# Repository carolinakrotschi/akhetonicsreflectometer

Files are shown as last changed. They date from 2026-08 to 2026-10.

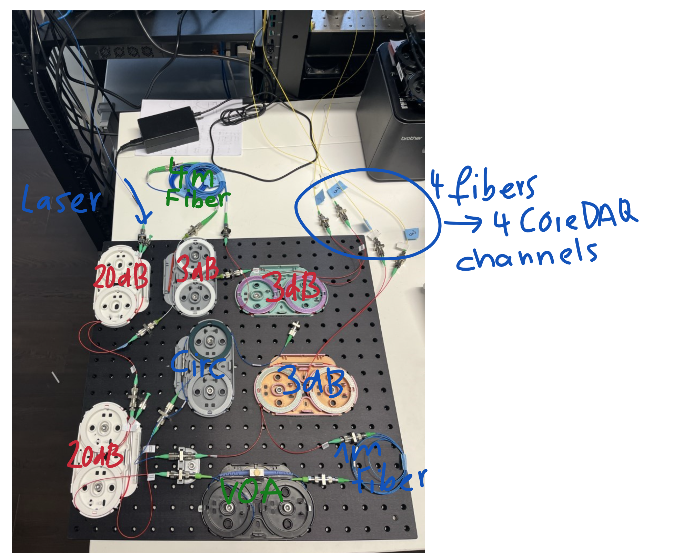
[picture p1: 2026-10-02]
general documents/setuplab.png

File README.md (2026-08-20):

# OFDR Reflectometer — what's in this folder

Quick orientation. For the physics/background, read `HANDOVER.md` first, then
`docs/handover_explained.md`. For the step-by-step lab procedure, see
`docs/measurement_procedure.md`.

## Active pipeline (main directory)

The setup as of 2026-08-18 uses the **old** trigger mode: EXFO laser sweep,
1 pm wavelength grid, 2 detector channels (Ch1/Ch2).

| Script | What it does |
|---|---|
| `process_reflectogram.py` | Main processing pipeline: loads an EXFO JSON scan, balances the two channels, corrects the frequency axis for the laser's tuning error, FFTs to a reflectogram, reports peak positions/widths, writes a CSV + PNG. This is the everyday tool. |
| `diagnose_artifacts.py` | Five discriminator tests for telling a real reflection apart from an artifact: `pm-am` (additive vs. multiplicative noise), `compare` (is a feature fixed/calibratable or a random per-scan realization?), `fold` (where would a reflector beyond Nyquist alias to?), `tuning` (measure the laser's actual sweep error), `alias` (single-file peak/aliasing-order check, or the definitive two-scan pair test with different wavelength steps). Run these *before* trusting an unexplained feature. |
| `plot_tuning_diagnosis.py` | Rebuilds the two-panel "MZI peak vs. sweep tuning error" figure (the one originally saved as `george/real_data_diagnosis.png`) for any scan, reusing `process_reflectogram.py`'s functions directly. |

The following three belong to the **new**, not-yet-built setup: free-running
acquisition with an auxiliary Mach-Zehnder interferometer ("aux MZI", the
"ruler") providing the frequency reference instead of a wavelength table,
4 channels. **Ch1/Ch2 = aux MZI (the ruler), Ch3/Ch4 = measurement
interferometer with the test fiber** (confirmed 2026-08-18 against the
real wiring — double-check this against the bench before trusting a scan).

| Script | What it does |
|---|---|
| `calc_sweep_parameters.py` | Desk calculator: given point count / sweep speed / span, computes resolution, Nyquist range, and whether the aux MZI's own signal fits inside that range. Use this before touching hardware. |
| `simulate_aux_data.py` | Generates synthetic 4-channel free-running data with *known* ground-truth reflector positions, including realistic imperfections (sweep bow, tuning ripple, gain drift, noise). Used to validate `process_reflectogram_aux.py` against a known answer before trusting it on real data. |
| `check_aux_interferometer.py` | Acceptance test for the aux MZI itself: contrast, monotonicity (laser must never tune backward), calibration (tau_aux via fringe counting), and laser quality (slow bow / fast ripple), measured cleanly through the aux signal. Run this before trusting anything the new setup measures. |
| `process_reflectogram_aux.py` | The new 4-channel processing pipeline: same balanced-subtraction/window/FFT/peak-report core as `process_reflectogram.py`, but the frequency axis comes from the aux MZI's phase instead of a wavelength table. |

## `tools/` — standalone helper scripts

Not part of the day-to-day pipeline above, but useful on their own.

| Script | What it does |
|---|---|
| `plot_band_comparison.py` | Compares the 6-32cm "dirt band" across several raw scans on one plot (built 2026-08-18 for the terminator investigation, see `raw_data/README.md`). |

(2026-08-18: `check_aliasing.py` was merged into `diagnose_artifacts.py` as
its `alias` subcommand — it overlapped with `fold`/`compare`/`pm-am` there.
`simulate_scan_data.py` and `plot_fsr_vs_wavelength.py` were retired as
dead weight — the former only validated the now-legacy CSV pipeline, the
latter was a one-off tied to a folder that no longer exists. All three are
still in git history if ever needed again.)

## `legacy/` — historical record only, no scripts left

`legacy/CHANGES.md` is the only thing left here: the documented bug list
from the very first (buggy) reflectometer attempt. The scripts themselves
(`reflectometer_v1_buggy.py`, `reflectometer_v2_fixed.py`, and the generic
CSV-based `reflectometer_csv_generic.py`) were all deleted 2026-08-18 as
fully superseded by `process_reflectogram.py` — recoverable from git
history if a plain-CSV or pre-EXFO-JSON input format is ever needed again.

## Other folders

- `raw_data/` — raw EXFO JSON scans, named `<date>_<condition>.json`; see `raw_data/README.md` for what each one is and the current findings.
- `results/<date>/` — generated CSVs and plots, one subfolder per day.
- `docs/` — explanatory and planning documents written for/with Carolina.
- `george/` — frozen reference copies of the files as originally handed over by the supervisor. Not used for running anything; the active copies above are what you actually execute.
- `logs/<date>.md` — daily work journal (see `CLAUDE.md` for the rule that maintains it).

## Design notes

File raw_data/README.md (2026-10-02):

# Raw data — file index

**Detector.** Every file listed below up to 2026-09-17 was recorded with the
Mk1 **LINEAR** coreDAQ demo unit. Since then both coreDAQs are Mk2 **LOG**
units (SN0001, SN0002). A Mk2 file carries a `detector` block in its header
(unit, serial, rate, clamp fractions, R(λ) correction); a file without one is
Mk1. For new entries add a column **Detector** (e.g. `Mk2 LOG SN0001,
100 kHz`) and note any clamp the recorder reported. Read all of them through
`tools/scan_io.py` -- see `md files/HANDOVER.md` §7.

**Scans from 2026-09-11 onwards ARE in the repository, as `.npz`.** The raw
`.json` still cannot be pushed -- each one is ~155 MB, past GitHub's hard
100 MB per-file limit -- but the same data stored as a compressed `.npz`
is 11-13 MB, a factor of ~13 smaller, and the conversion is **lossless**:
the four channel arrays are kept as float64 and verified bit-identical
after the round trip, and the wavelength axis is kept in full because it
turned out not to be linear (it deviates up to 0.147 nm from a straight
line). Converted with `tools/json_to_npz.py`; `process_reflectogram_aux.py`
reads `.npz` directly, and a reflectogram computed from the `.npz` is
bit-identical to one computed from the `.json`.

**Older raw JSON: not tracked in git** (`.gitignore`'d): with the current 1M-datapoint sweeps,
raw JSON scans run ~150 MB each, past GitHub's 100 MB file limit. Only the
`_trimmed1530.npz` derivative of each scan (produced during processing) is
committed. This file stays local-only; the mapping below is the record of
what exists on disk.

All files: EXFO sweep 1505.06-1624.96 nm, 119,921 points, old 1-pm trigger mode,
2 channels (Ch1/Ch2). Format: see `george/HANDOVER.md` section 2.

Note: `2026-08-20_laserdirektangeschlossen.json` uses power keys in `[W]`
(`"Ch1 [W]"` etc.), not `[mW]` like every other file listed here -- the
instrument apparently switches units depending on power range. Convert before
comparing medians against other scans.

| File | Date | Condition at the test port |
|---|---|---|
| `2026-08-18_open_end.json` | 2026-08-18 | No terminator, fiber end open (baseline, formerly `scan_s0.json`) |
| `2026-08-18_no_fiber.json` | 2026-08-18 | No test fiber connected at all (formerly `scan_s1new.json`) |
| `2026-08-18_terminator1.json` | 2026-08-18 | Terminator 1 |
| `2026-08-18_terminator2.json` | 2026-08-18 | Terminator 2 |
| `2026-08-18_10db_coupler.json` | 2026-08-18 | 10dB coupler inserted |
| `2026-08-19_firstscanwith4channels.json` | 2026-08-19 | First test scan, new 4-channel aux-referenced free-run setup (600 pts, 1505-1625 nm, Ch1/Ch2 = aux MZI, Ch3/Ch4 = measurement). Processed with `process_reflectogram_aux.py`. |
| `2026-08-19_secondscanwith4channelsmorepoints.json` | 2026-08-19 | Same setup, 60,000 pts, 1505-1625 nm. |
| `2026-08-19_1miodatapoints.json` | 2026-08-19 | Same setup, 1,000,000 pts, 1520-1570 nm (scan_S5 of `md files/measurement_procedure.md`). First 200,000 pts (wl<1530nm) are detector-saturated; drop them (`_trimmed1530.npz`) before trusting anything -- with them included, acceptance test **fails monotonicity** (2.4-25% backward steps depending on channel pairing, limit 0%). Channel-pairing investigation (see `logs/2026-08-19.md`/`logs/2026-08-20.md`): aux = Ch2/Ch4 (dL≈4.24m), measurement = Ch1/Ch3 -- opposite of the 2026-08-18 convention above. |
| `2026-08-19_deltaLwirklich1m.json` | 2026-08-19 | Same setup/format. Measurement-interferometer LO arm rebuilt to a real, physical ~1 m round-trip match (test fiber ~1.04 m one-way, confirmed by tape measure). Same first-10nm saturation as above; use `_trimmed1530.npz`. Aux calibration matches the scan above almost exactly (dL≈4.24m) -- confirms only the measurement arm changed. Reflectogram (aux=Ch2/Ch4, meas=Ch1/Ch3) shows the real fiber-end peak at ~1061.7mm (matches the measured 1.04m length within 2%) plus an unexplained dominant peak at ~587.0mm (not fiber-related -- stable across re-coiling, see next row) and two nonlinear mixing artifacts (~1649mm sum, ~2121mm 2nd harmonic of the fiber peak). |
| `2026-08-19_deltaLwirklich1mneugerollt.json` | 2026-08-19 | Same as `deltaLwirklich1m.json`, fiber only re-coiled (same physical fiber, different bend routing) -- otherwise nothing changed. Confirms: 587.0mm peak unchanged in position/strength (supports it not being the fiber); ~1062mm fiber peak same position, 11dB weaker (consistent with added bend loss); ~1649mm sum-artifact got 13dB *stronger* (unexplained -- inconsistent with simple intermodulation, possible real multipath reflection). |
| `2026-08-20_3mfiber.json` | 2026-08-20 | **"3mA" fiber** (label introduced 2026-08-31 to distinguish from the physically different "3mB" fiber used on 2026-08-31 -- inferred lengths differ, ~3147mm vs ~2616mm relative to connector). ~3m fiber moved onto the measurement interferometer as its only fiber (old ~1m fiber + LO-match arm removed); aux dL backfilled with 3x1m segments instead. Main 587mm-family peak persists (4th confirmation, internal artifact); nothing at naive 3000mm; unexplained peak at 3734.5mm (later shown to be fiber-related but not matching the tape-measured 3.05m length directly -- see log). |
| `2026-08-31-ohnefiberallesnormalerstemessungdestages.json` | 2026-08-31 | No fiber, first measurement of the day. Monotonicity FAILS (0.0224%, localized contrast dip). See `logs/2026-08-31.md`. |
| `2026-08-31-ohnefiberallesnormalzweitemessungdestages.json` | 2026-08-31 | No fiber, second measurement of the day (repeat). Monotonicity PASSES. |
| `2026-08-31-ohnefiberallesnormaldrittemessungdestages.json` | 2026-08-31 | No fiber, third measurement of the day (repeat). Monotonicity FAILS badly (0.93%, real sweep anomaly, not just noise) -- dL/tau_aux from this scan unreliable, do not reuse. |
| `2026-08-31-ohnefiberandereaux1mfiber.json` | 2026-08-31 | No fiber; the aux's 1m fiber segment swapped for a different physical one (dL essentially unchanged, ~3.59m; contrast/monotonicity improved). |
| `2026-08-31-ohnefiberaux5m.json` | 2026-08-31 | No fiber; aux stretched to dL≈4.489m (labeled "aux5m" target). Best contrast of the no-fiber scans that config. |
| `2026-08-31-ohnefiberaux6m.json` | 2026-08-31 | No fiber; aux stretched further to dL≈5.39m (labeled "aux6m" target). Points/fringe dropping toward the ~4 warning floor. |
| `2026-08-31-1mfiberaux5m.json` | 2026-08-31 | ~1m fiber (no separate letter label), aux5m config (dL≈4.489m). Inferred length ≈912mm relative to connector. |
| `2026-08-31-3mfiberaux5m.json` | 2026-08-31 | **"3mB" fiber** (see note on `2026-08-20_3mfiber.json` above), aux5m config (dL≈4.489m). Inferred length ≈2616.5mm relative to connector. |
| `2026-08-31-3mfiberaux4m.json` | 2026-08-31 | **"3mB" fiber** on the measurement arm, aux4m config (dL≈3.578m; **aux arm itself built from "3mA" + "1mB" segments** -- "3mA" being the old 2026-08-20 fiber repurposed as aux filler, "1mB" a separate 1m fiber, both distinct from the measurement-arm "3mB"/"1mA" naming below -- confirmed by Carolina 2026-08-31 after an initial mix-up). Same physical measurement fiber as the aux5m scan above, inferred length ≈2615.5mm, confirms length is aux-config-independent. |
| `2026-08-31-3mplus1mfiberaux4m.json` | 2026-08-31 | **"3mB" fiber + "1mA" fiber in series** on the measurement arm (the 1m component here labeled "1mA" to distinguish it from the standalone `1mfiberaux5m` fiber, which has no separate letter); aux4m config, aux arm built from "3mA"+"1mB" (see note above -- these are DIFFERENT physical fibers from the measurement arm's "3mB"/"1mA", despite the confusingly overlapping letters). Inferred combined length ≈3523.8mm, vs. 2615.5+912.0=3527.5mm predicted from the two measurement fibers measured separately -- within 4mm (this match is what confirmed the measurement arm is "3mB"+"1mA", not "3mA"+"1mB", after Carolina's initial statement suggested the latter). |
| `2026-08-31-3mplus1mfiberaux4m_2.json` | 2026-08-31 | Repeat of the scan above (same physical setup: measurement arm "3mB"+"1mA", aux arm "3mA"+"1mB"). dL=3.5778 m (tau_aux=17.5193 ns) -- matches the first scan's 3.5782 m to 0.4 mm, confirms the aux4m build is stable between scans. |
| `2026-08-20_nofiberattheend.json` | 2026-08-20 | No-fiber control: test-port fiber removed entirely, everything else (incl. 3x1m aux setup) left as in `3mfiber.json`. Proves the ~587mm and ~518mm peaks are fixed internal reflections, unrelated to any DUT fiber (both persist with nothing connected). |
| `2026-08-20_laserdirektangeschlossen.json` | 2026-08-20 | Laser output connected directly to a detector, bypassing the interferometer network entirely (control/reference scan, not a reflectogram). Only Ch2 carries signal (~5.800 mW, flat to ~0.03% across the whole 1520-1570nm sweep, **no saturation ramp at the start** unlike every interferometer scan); Ch1/Ch3/Ch4 sit at the electrical noise floor (~0.1-0.5 uW). Confirms the laser source itself is flat and clean -- the detector saturation seen in the first 200,000 points of other scans is caused downstream (interferometer/detector combination), not by the laser. Note: uses `[W]` units, see note above. Plot: `results/2026-08-20/2026-08-20_laserdirektangeschlossen_channels.png`. |
| `2026-08-20_nofiberattheendandnotthorlabsconnector.json` | 2026-08-20 | Second no-fiber control: same as `2026-08-20_nofiberattheend.json` (test-port fiber removed) but with the Thorlabs connector swapped for a different, "normal" (non-Thorlabs) connector -- **not removed, replaced** (corrected 2026-08-20, see log). Same 1M-point/4-channel/1520-1570nm format, same first-200,000-point saturation, trimmed the same way (`_trimmed1530.npz`). Big result: the dominant fixed-internal-reflection peak moved from ~587.8mm to **467.1mm** (0 dB) -- first evidence tying that peak's position to the physical path length of whichever connector occupies that slot. See `logs/2026-08-20.md` for the full writeup. |
| `2026-08-20_nofiberattheendandnotthorlabsconnectorandfibercleaned.json` | 2026-08-20 | Same setup as the row above (no fiber at test port, same replacement "normal" connector #1 still installed), plus the fiber was cleaned. Same format/trimming. Main peak essentially unchanged (467.0mm vs 467.1mm, negligible) -- confirms the fixed reflector is unrelated to fiber cleanliness, consistent with it not being fiber-related at all. Noise floor is ~9dB higher than the previous scan (median -59.2dB vs -68.4dB in a quiet 700-1600mm window), matching a lower aux contrast (min visibility 0.776 vs 0.846) -- explains why many more small peaks cross the fixed -50dB reporting threshold; not a new physical feature. See `logs/2026-08-20.md`. |
| `2026-08-20_nofiberattheendandnotthorlabsconnectorandfibercleanedandnewconnector.json` | 2026-08-20 | Same setup as the row above, but connector #1 was swapped for a SECOND, different "normal" connector (#2) -- so far: Thorlabs -> normal connector #1 -> normal connector #2, never actually connector-free. Same 1M-point/4-channel/1520-1570nm format, but **saturation ramp lasts ~13nm this time** (vs ~10nm on every earlier 2026-08-20 scan) -- trimmed to `_trimmed1533.npz` (dropped first 260,000 pts, wl<1533nm) instead of the usual `_trimmed1530.npz`. Big result: main peak moved back to **589.7mm**, into the same ~587-590mm family seen throughout the day with the ORIGINAL Thorlabs connector in place -- confirms the peak's position tracks the physical path length of whichever connector occupies that slot (connector #2's length happens to be close to the Thorlabs one's; connector #1's was ~120mm shorter), not the identity of one specific connector. The ~518-521mm secondary cluster also reappeared. See `logs/2026-08-20.md` for the full writeup and `HANDOVER.md` section 2 for the updated standing conclusion. |
| `2026-08-20_nofiberattheendandnotthorlabsconnectorandfibercleanedandnewconnectorneueeinschwingzeit.json` | 2026-08-20 | Same nominal setup as the row above (connector #2), but recorded AFTER a fix to the akhelabs acquisition software (`exfo_window.py`): a new "Settle margin (nm)" field makes the laser start its physical sweep that many nm before the requested start wavelength, then crops the pre-roll back out after acquisition -- so the returned data no longer contains the ~10-13nm detector-saturation transient at all. 833,333 points, 1520.00-1570.00nm, no wavelength trim needed (saved whole as `_full.npz`, verified clean in 0.5nm bins from the very first sample). Resolution improved from 22.61um (previous scan, 13nm had to be trimmed) to **16.59um** (full ~50nm span used) -- see `logs/2026-08-20.md` for the comparison plot. Note: aux dL (3.593m) and the main peak position (495.6mm) both differ noticeably from the immediately preceding connector-#2 scan (4.276m / 589.7mm) -- the physical setup was evidently touched again while testing the new firmware feature; not yet reconciled, see log. |

| `2026-09-11-11-36_3mfiber.json` | 2026-09-11 | ~3 m fiber on the measurement arm, LinaWindow/coreDAQ-LIN, 1520-1570 nm. **Not yet processed** -- recorded 40 min before the chip scan below, same session. |
| `2026-09-11-12-16hhi1fiber7.json` | 2026-09-11 | **Sixth HHI chip measurement -- fiber 7 = `b25`, the STUB negative control. Passed.** Facet A at 1673.3662 mm (0 dB, -3 dB width 33.2 um vs 43.1 um window limit = isolated single reflector), pigtail 1099.492 mm, noise floor -69.2 dB, and **nothing behind facet A** beyond the satellite skirt (max -40 dB in +5..+12 mm, -44 dB in +20..+60 mm). Three conclusions: (1) the rule **b = 32 - fiber** is confirmed a second time, independently of any path-length assignment; (2) **there is no "SSC-internal reflector" at +3.1..3.7 mm** -- a stub contains a full SSC and shows nothing there, so that earlier interpretation is retracted; (3) **"strongest peak = facet A" does not hold generally** -- facet A is the fiber/chip interface reflection, set by glue/gap/index match alone, and varies by >45 dB across channels (+36 dB vs the internal reference here, -9 dB in the top loopback), so facet A must be identified via the pigtail-length family (1094.4..1099.5 mm over 6 fibers), not via peak height. tau_aux = 20.3811 ns, monotonicity passes. |
| `2026-09-11-12-16hhi1fiber30.json` | 2026-09-11 | **Fifth HHI chip measurement -- fiber 30.** Cleanest scan of the day (noise floor -71 dB, single reflector with -3 dB width 49.8 um vs 43.1 um window limit). Facet A at 1670.2383 mm (pigtail 1096.312 mm), one dominant reflector at **+9.2069 mm = 2685.8 um of on-chip waveguide -- which matches NO channel in the layout** (nearest path end is b3 at 2489.6 um, 28 resolution cells away). **This refutes the "fiber 27 was a misread 30" hypothesis**: the two scans have different pigtails (1095.32 vs 1096.31 mm) and different dominant reflectors (+14.6148 vs +9.2069 mm), so they are different couplers. **Consequence: the n_SSC/n_waveguide split reported from the 3-point fit is RETRACTED** -- it relied on assigning the +14.6148 mm peak to b2's MMI input, which no longer holds; that 2.3 um agreement was most likely coincidence. What stands: n_g,chip = 3.4803 +- 0.008 from the two loopbacks alone. tau_aux = 20.3808 ns, monotonicity passes. |
| `2026-09-11-12-16hhi1fiber6.json` | 2026-09-11 | **Fourth HHI chip measurement -- fiber 6.** Confirms the fiber-to-coupler rule **b = 32 - fiber** (position from top = fiber - 3, 29 couplers on fibers 4..32): without the +3 offset fiber 6 would be `b23`, a stub with 18 um of waveguide, which cannot produce the observed -1.31 dB peak 15 mm into the chip plus a 70 mm forest of 448 peaks. Quantitatively consistent with `b26` (run 5126.8 um, implied pigtail 1095.84 mm) but **not separable from b2** -- they differ by 0.378 mm while the multipath forest (mean peak spacing 0.156 mm) limits facet-A anchoring to +-0.4 mm. Methodological lesson: **circuit channels are unusable for precision work** (decoder has many MMIs + 2 ring resonators -> recirculation); only the two loopback pairs give clean geometry. tau_aux = 20.3815 ns, monotonicity passes. |
| `2026-09-11-12-16hhi1fiber27.json` | 2026-09-11 | **Third HHI chip measurement -- single-ended channel, fiber 27.** Named "kanal24" but the measurement identifies it as **GDS coupler `b2`**, not b24: facet A at 1669.3593 mm (fiber 1095.316 mm), dominant peak (0 dB, the strongest in the whole scan) at +14.6148 mm = the input facet of an MMI 1x2 splitter at the end of b2's 4967.278 um waveguide run -- predicted 14.6214 mm, i.e. **6.6 um off over 14.6 mm (0.045%)**. tau_aux = 20.3814 ns, monotonicity passes, best contrast of the day (0.640). Combined with the two loopback scans this gives 3 measurements for 2 unknowns: **n_g,SSC = 3.4808 +- 0.0121 and n_g,waveguide = 3.4782 +- 0.0078, agreeing to 0.07%** -- so SSC and waveguide have the same group index and the uniform-n_g assumption holds. Fiber-to-channel mapping still unconfirmed; the only simple rule matching fiber 27 -> b2 is fiber n -> b(29-n). |
| `2026-09-11-12-16hhi1fiber32.json` | 2026-09-11 | **Second HHI chip measurement -- the BOTTOM loopback pair `b0`/`b1`** (design loop 556.5494 um, chip path 2956.55 um), same setup as the scan below, only re-plugged to the other coupler pair. 988,536 pts, 1520-1570 nm. tau_aux = 20.3807 ns (stable to 0.01% vs the top-loop scan), monotonicity passes. Facet A 1668.3752 mm (-16.6 dB), facet B 1675.3923 mm (-4.1 dB) -> **chip path dz = 7.0171 mm -> n_g,chip = 3.4842**, which agrees with the top pair's 3.4765 to **0.22%**. Differential vs the top pair: dz shrinks by 0.1825 mm for an 83.577 um shorter design loop = **77.0 um of on-chip waveguide measured SSC-free** (one resolution cell = 7.0 um physical). The middle reflectors stay put in both scans -> SSC-internal, not the loop ends. Pigtails here: 1094.4005 / 1095.1139 mm (per-channel, glued). Couples better than the top pair. |
| `2026-09-11-12-16hhi1fiber4.json` | 2026-09-11 | **First HHI chip measurement -- the TOP loopback pair `b27`/`b28`.** Measurement arm = MZI -> ~1 m fiber (SQS Vlaknova Optika, FC/APC, SM, no. 0103254561) -> HHI chip 1, **both** edge couplers of the top-left pair are pigtailed with ~1 m fibers (measurement arm -> fiber 1 -> chip loop -> fiber 2 -> open end, which provides the back-reflection); on-chip link is the 640.13 um loop (see `logs/2026-09-11.md` for the GDS length extraction). 988,536 pts, 1520-1570 nm. tau_aux = 20.3809 ns (dL = 4.1622 m), monotonicity passes (0.0000%). Chip input facet at 1670.23 mm (-9.1 dB) = +1096.30 mm past the fixed internal 573.93 mm reference; chip end facet at +7.200 mm, two intermediate reflectors at +3.135/+4.064 mm (2x3.135+0.929 = 7.199, symmetric 3-section path = SSC + loop + SSC). Full path vs. design 3040.13 um gives n_g,chip = 3.477. Open end of fiber 2 found at 2773.625 mm (-36.8 dB) = +1096.199 mm past the chip, i.e. **the two ~1 m fibers match to 0.099 mm** (1096.298 vs 1096.199 mm) -- independent confirmation of the whole chain. The +-0.70/+-1.53 mm satellites are instrument artifacts (ring the 573.93 peak identically). |

**Finding (6-32cm band, see `results/2026-08-18/band_6_32cm_comparison.png`):**
Terminator 1, Terminator 2, and the 10dB coupler all sit at approx. -52 to
-54 dB — essentially identical to `open_end` (-52.6 dB). Only `no_fiber` is
noticeably lower (-68.8 dB, noise floor). None of the tested terminators
effectively suppresses the reflection; the suspicion falls on Rayleigh
backscatter along the whole patchcord, or the near-end connector
(circulator <-> patchcord), rather than the far end. Next test discussed:
a short patchcord (<35 cm) to distinguish between the two hypotheses.

An earlier terminator attempt (`scan_s1.json`, deleted before 2026-08-18) had
an even louder band (-35.8 dB) — cause unresolved, file no longer available.

**Test fiber length (2026-08-18):** confirmed 50 cm one-way (1 m round trip).
`python diagnose_artifacts.py fold 0.5` shows this is BEYOND the old setup's
Nyquist range (0.417 m) and folds to **0.334 m (33.4 cm)** as an undersampled
band (1.67 points/fringe) — right at the edge of the observed 6-32cm dirt
band. This means the far-end reflection itself likely IS a real contributor
to that band (aliased, not resolvable), on top of/instead of the Rayleigh
backscatter hypothesis above. With the current 1-pm trigger mode, no
terminator or connector fix can turn this into a clean peak — the fiber is
simply longer than this mode can resolve unambiguously. The Aux-referenced
setup (~7 m Nyquist range) is required to see it cleanly at its true 50 cm
position.

**Open discrepancy:** confirmed 2026-08-18 to be the same physical patchcord
as the one behind the ~1.046 m estimate in `HANDOVER.md` §5 (2026-08-12) --
but the two lengths don't reconcile by a simple convention mixup (`fold 0.5`
and `fold 1.046` predict different apparent band positions). See the
"Test fiber length" note in `HANDOVER.md`'s hardware section for the
candidate explanations and the suggested `alias` pair test to settle it.

## Ligentec-SiN-Chip (Faserarray an der unteren Kante, 95 Kanaele)

**Chip-Praefix-Konvention (ab 2026-09-16):** alle Scans bis einschliesslich
2026-09-15 stammen vom selben physischen Chip, **MAP2672** -- ihre
rawdata- und results-Dateien wurden deshalb nachtraeglich mit
`2672_ligentechhi_` praefigiert. Ab 2026-09-16 wird ein neuer Chip,
**MAP2680**, vermessen; neue Scans dieses Chips sollten entsprechend mit
`2680_ligentechhi_` beginnen, damit rawdata/results-Dateinamen allein
erkennen lassen, von welchem physischen Chip sie stammen. Ausgenommen von
der 2672-Umbenennung: `raw_data/hhi_ligentec/` (gemeinsame GDS-Designdatei,
nicht chipspezifisch) und die `..._2m07cmfiber...`-Scans (laut Tabelle
unten explizit **kein Chip** angeschlossen).

**MAP2680 traegt elektrische Kontakte (Bondpads/Leiterbahnen), MAP2672
nicht.** Auch unangeschlossen koennen sie die Reflektogramm-Struktur nahe
der Facette beeinflussen (zusaetzliche Streuzentren/Reflexe durch
Metallisierung). Erster Hinweis 2026-09-16: Faser 1 auf beiden Chips zeigt
in der auf den eigenen Peak zentrierten Ansicht rechts vom Peak aehnliche,
links vom Peak abweichende Struktur -- siehe `logs/2026-09-16.md`. Noch
nicht verifiziert (z.B. gegen GDS-Kontaktlayout oder einen Kontrollscan);
offene Hypothese, beim Interpretieren chipuebergreifender Strukturvergleiche
mitdenken.

Alle Scans: neuer PM-Aufbau, freilaufend, 4 Kanaele (Ch2/Ch4 = aux,
Ch1/Ch3 = Messung), **1520.00-1570.00 nm, 988,536 Punkte**, tau_aux
~20.633 ns (aux dL 4.21 m). Aufloesung 16.6 um faseraequivalent,
Nyquistbereich 8.0 m. Kanalnummer = 96 - Fasernummer.

Gemeinsamer interner Anker fuer alle diese Scans: **529.43 mm**; auf ihn
werden die Pegel normiert, weil die alten Anker (574/587 mm) nach dem
PM-Umbau weg sind.

| File | Datum | Faser -> Kanal | Was dahinter liegt | Facette A |
|---|---|---|---|---|
| `2672_ligentechhi_2026-09-14-16-19_ligentecnofiber.json` | 2026-09-14 | — | **Kontrolle**, nichts angeschlossen | — |
| `2672_ligentechhi_2026-09-14-16-02_Ligentecfiber1.json` | 2026-09-14 | 1 -> 95 | Loopback 199.494 um zu Kanal 94 | 1582.818 mm |
| `2672_ligentechhi_2026-09-14-16-36_Ligentecfiber44.json` | 2026-09-14 | 44 -> 52 | Schaltung, 1x2-MMI nach 8912 um | 1580.416 mm |
| `2672_ligentechhi_2026-09-14-16-41_Ligentecfiber45.json` | 2026-09-14 | 45 -> 51 | Schaltung, wie Kanal 52 an comp265 | — |
| `2672_ligentechhi_2026-09-14-16-50_Ligentecfiber45neu.json` | 2026-09-14 | 45 -> 51 | Wiederholung von 16:41 | — |
| `2672_ligentechhi_2026-09-15-08-19_ligentecfiber45wavelenght1520to1570nm.json` | 2026-09-15 | 45 -> 51 | Wiederholung, Standardspanne | — |
| `2672_ligentechhi_2026-09-15-08-19_ligentecfiber45wavelenght1505to1625nm.json` | 2026-09-15 | 45 -> 51 | **Ausnahme: 1505-1625 nm**, volle Spanne | — |
| `2672_ligentechhi_2026-09-15-09-34_Ligentecfiber48.json` | 2026-09-15 | 48 -> 48 | Schaltung; der Kanal, der in **Transmission** Signal gibt (Laser 48 -> PM 49) | 1582.141 mm |
| `2672_ligentechhi_2026-09-15-09-34_Ligentecfiber48fnotfullwavelenghtremeasure.json` | 2026-09-15 | 48 -> 48 | Wiederholung, Standardspanne 1520-1570 nm | Facette 1585.712 mm |
| `2672_ligentechhi_2026-09-15-09-34_Ligentecfiber48fullwavelenght.json` | 2026-09-15 | 48 -> 48 | **Ausnahme: 1505-1625 nm**, volle Spanne | Facette 1585.669 mm |
| `2672_ligentechhi_2026-09-15-09-34_Ligentecfiber48fullwavelenghtremeasure.json` | 2026-09-15 | 48 -> 48 | **defekt** -- JSON bricht bei Zeichen 356 457 004 mitten in der Zahlenliste ab (Aufnahme unterbrochen) | -- |
| `2672_ligentechhi_2026-09-15-09-34_Ligentecfiber48fullwavelenght_ipa.json` | 2026-09-15 | 48 -> 48 | volle Spanne, **mit IPA** (Bedeutung noch nicht dokumentiert -- vermutlich Indexanpassung an der Facette) | Facette 1585.670 mm |
| `2026-09-15-08-19_ligentec2m07cmfiberwavelenght1520to1570nm.json` | 2026-09-15 | — | **kein Chip**, nur eine 2.07-m-Faser am Port | Faserende 2642.975 mm |
| `2026-09-15-15-14meisusmfiberarrzchannel4.json` | 2026-09-15 | Meisu-Array, Kanal 4 | **anderes Faserarray**, kein Ligentec-Chip | Arrayfacette 1632.68 mm |
| `2026-09-15-15-14meisusmfiberarrzchannel4remeasure.json` | 2026-09-15 | Meisu-Array, Kanal 4 | Wiederholung von Kanal 4, neu gesteckt | Arrayfacette 1632.52 mm |
| `2026-09-15-15-14meisusmfiberarrzchannel8.json` | 2026-09-15 | Meisu-Array, Kanal 8 | dito | Arrayfacette 1633.31 mm |
| `2026-09-15-15-14meisusmfiberarrzchannel9.json` | 2026-09-15 | Meisu-Array, Kanal 9 | dito | Arrayfacette 1633.42 mm |
| `2026-09-15-15-14meisusmfiberarrzchannel12.json` | 2026-09-15 | Meisu-Array, Kanal 12 | dito | Arrayfacette 1632.44 mm |
| `2026-09-15-15-14meisusmfiberarrzchannel12remeasure.json` | 2026-09-15 | Meisu-Array, Kanal 12 | Wiederholung von Kanal 12 | Arrayfacette 1632.56 mm |
| `2026-09-15-15-14phixsmfiberarrzchannel1.json` | 2026-09-15 | PHIX-Array, Kanal 1 | **drittes Faserarray**, kein Ligentec-Chip | Arrayfacette 1624.55 mm |
| `2026-09-15-15-14phixsmfiberarrzchannel8.json` | 2026-09-15 | PHIX-Array, Kanal 8 | dito | Arrayfacette 1626.19 mm |
| `2026-09-16-10-36_ligentec2680_fiber1.json` | 2026-09-16 | **MAP2680**, 1 -> 95 | erster Scan neuer Chip, Standardspanne | Facette 1581.697 mm |
| `2026-09-16-10-36_ligentec2680_fiber1full.json` | 2026-09-16 | **MAP2680**, 1 -> 95 | volle Spanne 1505-1625 nm | Facette 1581.696 mm |
| `2680_ligentechhi_20260916-105948_fiber44_1520-1570nm.json` | 2026-09-16 | **MAP2680**, 44 -> 52 | Standardspanne | Facette 1579.112 mm |
| `2680_ligentechhi_20260916-110010_fiber44_1505-1625nm.json` | 2026-09-16 | **MAP2680**, 44 -> 52 | volle Spanne | Facette 1579.129 mm |
| `2680_ligentechhi_20260916-110152_fiber48_1520-1570nm.json` | 2026-09-16 | **MAP2680**, 48 -> 48 | Standardspanne | Facette 1579.172 mm |
| `2680_ligentechhi_20260916-110214_fiber48_1505-1625nm.json` | 2026-09-16 | **MAP2680**, 48 -> 48 | volle Spanne | Facette 1579.127 mm |

`.npz` vorhanden bisher nur fuer `2672_ligentechhi_2026-09-15-09-34_Ligentecfiber48`; die
2026-09-14er Ligentec-Scans und die acht Array-Scans (Meisu 4/8/9/12 plus
Wdh. von 4 und 12, PHIX 1/8) sind noch nicht konvertiert und existieren
nur lokal als `.json`.

Befund ueber alle Kanaele: ausser der Facettenreflexion selbst kommt
**nichts aus dem Chip zurueck** -- siehe `logs/2026-09-14.md` und
`logs/2026-09-15.md`. Pruefwerkzeuge:
`tools/check_ligentec_channel.py` (Vorhersagefenster + zwei Kontrollen)
und `tools/compare_ligentec_channels.py` (Zentrierung auf Facette A +
Nullverteilung).

## 2026-10-01 -- erste Mk2-Messung (2m07-PM-Faser)

Rohpuffer aus `lina_sweep_test` (ganzer Armierungspuffer, 1 050 000 Samples
x 4 Kanaele in mW, `meta` mit `detector`). Nach dem Sweep (9.89 s) faehrt der
Laser im Puffer zurueck -- `tools/scan_io.py` schneidet das ueber die
Aux-Frequenz ab. Auswertung: `logs/2026-10-01.md`,
`results/2026-10-01/mk2_reference/`.

| Datei | Detektor | Zustand | Befund |
|---|---|---|---|
| `sweep_ofdr_mk2_2m_run{1,3,5,7,8,9}_2026-10-01_*.npz` | Mk2 LOG SN0002, 100 kHz, Klemme 0 % | 2m07-PM-Faser (dieselbe wie 2026-09-15) am Messport, Ende offen | Stecker 2710.1 mm (−20.6 dB), Ende = drei Peaks 4806.2 / 4807.7 / 4809.4 mm; L = 2.0976 m (n_g 1.468) |
| `sweep_ofdr_mk2_nofiber_run{1,2,3}_2026-10-01_*.npz` | dito | ohne Faser, offener Stecker | Stecker 2709.98 mm (0 dB), 3. Harmonische gefaltet bei 7.946 m (−33 dB) |
| `gui_response_sweep_2026-10-01_10-49-52.npz` | **kein Header** | GUI-Test: beschnitten, λ-Achse, R(λ)-korrigiert | keine Rohdaten, nicht ausgewertet |

## 2026-10-02 -- ohne 20-dB-Koppler, VOA im LO-Arm gegen 2-m-Faser

GUI-Captures (Lina, aux-Achse, R(λ)-korrigiert), 1505–1625 nm, verlustfrei
aus `.json` konvertiert. Gegenueber 10-01 ist der 20-dB-Koppler hinter dem
Zirkulator (1 % -> 2-m-Referenz) ausgebaut. Auswertung: `logs/2026-10-02.md`,
`results/2026-10-02/ofdr_report_no_offset/`.

| Datei (`2026-10-02-11-…npz`) | Detektor | Zustand | Befund (Odyssey-Report) |
|---|---|---|---|
| `nofiberattheendandnoextra2m` | Mk2 LOG SN0002, 240 kHz, Klemme 0 % | ohne Faser, VOA im LO-Arm | Port 557.18 mm (0 dB), kein Ende |
| `2mfiberattheendandnoextra2m` | dito | 2m07-PM-Faser am Port, VOA im LO-Arm | Port 557.17 mm, L = 2095.95 ± 0.21 mm |
| `nofiberattheendandnoextra2mandswapvoafor2mfiberinmeasurementmzi` | dito | ohne Faser, 2-m-Faser statt VOA | Port 585.58 mm (LO 56.8 mm kuerzer), kein Ende |
| `1mCfiberattheendandnoextra2mandswapvoafor2mfiberinmeasurementmzi` | dito | 1mC-SM-Faser am Port, 2-m-Faser statt VOA | Port 585.58 mm, L = 1056.51 ± 0.11 mm (09-15: 1056.42) |

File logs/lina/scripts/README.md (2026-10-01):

# Scripts

Seven command-line tools. All of them run from the
repository root and expect the Lina hardware (`exfo-1` + the paired coreDAQ,
plus `tof1550-1` for the calibration) to be free — close AkheLab first, since
LabDevice allows one instance per serial id and the coreDAQ's USB port is
exclusive.

Reasoning behind every design decision: `../report.md`.

---

## The coreDAQ: Mk2 LOG since 2026-09-17

Everything up to 2026-09-17 was measured with the Mk1 **LINEAR** demo unit.
Both coreDAQs are now **Mk2 InGaAs LOG** units (`coredaq-1` = SN0001,
`coredaq-2` = SN0002), told apart only by serial. What that means here:

- **Which unit:** `coredaq_name` of `lina-1` in `Interface/config/OBR_config.json`.
  The GUI preselects it and every script's `--coredaq` defaults to it, so
  re-cabling is that one edit. The driver resolves the port by serial and
  refuses a unit whose serial does not match.
- **Capture mode** is no longer inferred from the variant. The GUI has a
  *Continuous (OFDR)* / *Stepped* combo, defaulting to continuous; the scripts
  were always continuous.
- **Needs py-coredaq 2.4.0** (`requirements.txt`). 1.2.1 rejects Mk2 firmware
  v1.6 with an error advising a firmware update — do **not** flash, it may
  cost the 1 MS/s tier.
- **The signal is still mW**, linearised from the device's 128-point LUT, but:
  no autorange jumps; noise roughly constant in dB (relative) rather than
  constant in mW; never negative — dark samples sit on a clamp floor; and a
  **silent clamp at ~3 mW** (no over-range flag). The GUI and the scripts
  (`run_sweep`, so also `lina_chip_measure` / `lina_voa_series`) count samples
  on either clamp and write it to the saved header / NPZ meta (`detector`,
  built by `lina/analysis/lina_detector.py`); the scripts also print a warning.
  A clamped fringe shows up in OFDR as ghost peaks at multiples of the real
  delay.
- **Bandwidth depends on photocurrent:** 150 kHz above ~10 nW, 50 kHz at 1 nW,
  unspecified below. Fringes at 5 nm/s are ~13 kHz (aux) and ~22 kHz (3 m fibre),
  so this only bites if fringe minima drop below ~1 nW.
- **Rate:** up to 1 MS/s on the HIGH tier (GUI ceiling follows the unit). At
  that rate the ~150 kHz analog bandwidth, not Nyquist, limits the delay range.
- **Responsivity correction** (`λ-cal correction` in the GUI) is now active on
  the continuous path; the scripts stay raw (see `lina_chip_measure.py`). The
  GUI stores the factor's ingredients in `detector.responsivity_correction`,
  so an analysis can divide it back out and compare GUI captures with raw ones
  (the reflectometer repo's `tools/scan_io.py` does that by default).
- **To confirm on first use:** repeat a reference capture (1 m / 3 m patch
  cord, 1520–1570 nm, 5 nm/s, 100 kHz) against 1.0397 m / 3.0256 m, and re-run
  one TOF1550 calibration to check the λ(t) fit carried over from the Mk1.

---

## Why these exist as scripts and not only as GUI features

The GUI could not be debugged interactively from a terminal session, and the
problem being investigated (a wrong wavelength axis) needed dozens of captures
with varied processing. A script gives that; a Qt window does not. The
processing itself lives in `../analysis/`, so the GUI and these scripts share
one implementation and cannot drift apart.

---

## `lina_sweep_test.py` — capture and wavelength calibration

The headless version of the Lina Response Sweep (the continuous coreDAQ path),
plus the λ(t) calibration workflow.

| Subcommand | Purpose |
|---|---|
| `sweep` | One raw, uncropped capture + diagnostics. With `--cal`, reports where a marker lands on the calibrated axis versus the naive one. |
| `filter-cw` | Steps the laser in CW across the TOF1550 passband → the filter's true peak wavelength, independent of the filter's own setting error. |
| `calibrate` | For each filter position: optional CW ground truth + a sweep, locating the marker in time. Fits λ(t), reports effective sweep rate and dead time, and publishes the result to `../calibrations/`. |
| `repeat` | N identical sweeps with the filter parked — run-to-run jitter and drift. |
| `refit` | Re-fits a saved calibration at another polynomial degree (no hardware). |
| `plot-cal` | Plots a saved calibration: fit, residuals, naive-axis error. |
| `apply` | Re-plots a saved capture on a calibrated axis. |

```bash
python lina/scripts/lina_sweep_test.py --channels 2 calibrate \
    --start 1520 --stop 1570 --speed 5 --rate 5000 --trust-filter \
    --filter-positions 1530,1535,1540,1545,1550,1555,1560,1565
```

Keep calibration runs at a few kHz: the fit is in seconds, so it applies at
100 kHz anyway, and the smaller USB transfer is far less likely to stall.

---

## `lina_ofdr_test.py` — OFDR measurement and evaluation

Captures all four channels and turns the two MZI channel pairs into distance
spectra.

| Subcommand | Purpose |
|---|---|
| `measure` | Capture + process + plot in one go. |
| `process` | Re-process a saved capture (different window, padding, channel roles). |
| `peaks` | Both spectra of one capture, stacked: aux above, measurement below. |
| `overlay` | Several captures in one figure, one colour each. |

Options worth knowing:

- `--meas 1,3 --ref 2,4` — channel roles (defaults match this setup).
- `--offset-m` / `--meas-offset-m` — subtract the interferometer's own path
  imbalance so the axis reads test-fibre length.
- `--convention reflection|transmission` — factor 2·n_g or n_g. Reflection is
  the default because the test fibre here is traversed twice.
- `--decimate 3000` — block-maximum ("peak hold") display: peaks keep their
  exact height while the noise collapses to a thin line.
- `--n-group 1.4682` — every length scales linearly with this.

```bash
python lina/scripts/lina_ofdr_test.py --tag myrun measure \
    --start 1520 --stop 1570 --speed 5 --rate 100000
```

---

## `lina_window_test.py` — headless GUI hardware test

Builds the **real** `LinaWindow` with the real `DeviceRegistry` on Qt's
offscreen platform and drives it like a user: selects the capture device, ticks
channels, presses "Response Sweep" (and with `--ofdr`, "OFDR Plot"). The
capture runs through the GUI's own worker, so this tests the GUI rather than a
copy of it.

```bash
python lina/scripts/lina_window_test.py --channels 1,2,3,4 --ofdr
```

This is what found the `"aux"`-in-the-mode-parameter bug and the premature-read
bug (`../report.md` §4.1, §10, §11).

---

## `lina_chip_measure.py` — a guided measurement session

The Lina GUI's Response Sweep, repeated over channels and sweep windows without
the clicking. It asks which channel(s) to measure, then per channel: prompts
for the patch change with the emission off, runs every window unattended, and
names the files itself. Afterwards it asks again, so one session covers as
many channels as you like; an empty answer ends it.

Same capture path as `lina_sweep_test sweep`, same Auto-fit sample count as
the GUI, same wavelength axis (λ(t) calibration → aux fringe → linear).

```bash
python lina/scripts/lina_chip_measure.py --dry-run          # the plan, no hardware
python lina/scripts/lina_chip_measure.py --chip 2680 --label ligentechhi
python lina/scripts/lina_chip_measure.py --fibers 44,48 --connected 44
```

One `<chip>_<label>_<YYYYmmdd-HHMMSS>_fiber<NN>_<window>.npz` per capture in
`--out` (default `lina/raw_data`), plus a quicklook PNG. The NPZ layout is the
one `load_raw` reads, with the wavelength axis in `wl_nm` and the crop it
belongs to in `meta["crop"]`, so the OFDR tools take these files directly:

```bash
python lina/scripts/lina_ofdr_test.py peaks --raw lina/raw_data/<file>.npz
```

---

## `lina_voa_series.py` — a VOA attenuation series

Ten (or N) identical wide-window sweeps on one fibre, one per setting of the
manual variable optical attenuator. It stops before every capture, shows the
live CW power so the knob can be turned to a visible level, and records what
you type there as that capture's VOA setting — so the setting ends up in the
file rather than in your memory.

Same capture path, wavelength axis and NPZ layout as `lina_chip_measure.py`,
whose helpers it imports rather than copies. Always the wide 1505–1625 nm
window, which has no λ(t) calibration and is carried by the aux fringe.

```bash
python lina/scripts/lina_voa_series.py --dry-run        # the plan, no hardware
python lina/scripts/lina_voa_series.py --fiber 48 --runs 10
python lina/scripts/lina_voa_series.py --fiber 48 --start-index 8 --runs 3
```

Files are `<chip>_<YYYYmmdd-HHMMSS>_fiber<NN>_fullnmrange_<i>.npz`, the
timestamp being the session's, so a series is one contiguous block of names
differing only in the trailing index. Two figures close it: `_stacked.png`
(one panel per run, shared axes) and `_levels.png` (mean power against run
index). The stacked figure is linear with a min/max envelope up to ~13 dB of
spread and logarithmic with peak hold past it — `--log-y` / `--linear-y`
force either.

`--replot "<glob>"` rebuilds both figures from saved NPZs without hardware, so
a session interrupted at run 7 still gets its figure.

---

## `lina_npz_to_json.py` — captures in the house JSON format

Turns the NPZs into `{"header": …, "data": [{…}]}` JSON, the format the rest of
AKHExperiment stores measurements in and the one the GUI's "Save Data" writes.
No hardware, so it can be run long after the session.

```bash
python lina/scripts/lina_npz_to_json.py                 # all of lina/raw_data
python lina/scripts/lina_npz_to_json.py --out L:/Measurements/2680 <file>.npz
```

Columns are cropped to `meta["crop"]`, so `Wavelength [nm]` and the `Ch<n> [mW]`
columns all have the same length. It is text: ~50 MB per 1 M samples, ~123 MB
per 2.4 M. Numbers are written at 1 fm / 6 significant figures, past what the
instruments resolve but well short of float64's 17 digits.

---

## `lina_cal_summary.py` — one overview figure

Reads only saved files, no hardware. Six panels: filter passband, raw capture
with the sweep window marked, the λ(t) fit, residuals per degree, the axis-error
comparison, and stability over time.

```bash
python lina/scripts/lina_cal_summary.py --data lina/data/01_wavelength_calibration
```

---

## Note on the data folders

The scripts write into whatever `--out` points at (defaults: `lina_cal_data`,
`lina_ofdr_data`, `lina_gui_test` relative to the working directory). The data
recorded on 2026-09-01 was moved into `../data/` afterwards; pass `--out` to
write there directly, e.g.
`--out lina/data/02_ofdr_measurements`.

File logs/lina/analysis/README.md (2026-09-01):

# Analysis modules

The processing shared by the scripts in `../scripts/` and the Lina window in
`LabGUI/dashboards/instruments/lina_window.py`. It lives here, in one place, so
the GUI and the scripts cannot drift apart — a divergence between them would be
invisible and would silently produce different lengths from the same data.

Reasoning: `../report.md`, §3 and §6.

---

## `lina_wl_cal.py` — the λ(t) wavelength axis

A LINEAR coreDAQ capture is one free-running buffer started by a single trigger
edge, so every sample carries a **time**, not a wavelength. This module holds
the measured mapping from time to wavelength and its application.

| Function | Purpose |
|---|---|
| `fit_time_to_wavelength(times, wavelengths, degree)` | The fit. Degree 2 measured at 3.1 pm rms. |
| `find_calibration(start, stop, speed)` | Looks up the calibration for one sweep configuration in `../calibrations/`. Returns `None` rather than guessing — a calibration from a different configuration is worse than none, because it is silently wrong. |
| `wavelength_axis(cal, n_pts, rate_hz)` | Wavelength per sample. Rate-independent: the fit is in seconds, so a 5 kHz calibration applies to a 100 kHz capture (verified to −3 pm). |
| `sweep_window(cal, n_pts, rate_hz)` | Which part of the buffer is the sweep. Measured: t = 0.004 … 9.889 s of a 12.00 s capture; everything after is the return slew. |
| `apply_calibration(cal, traces, rate_hz)` | Both of the above, cropping the traces consistently. |

Tolerances for matching a stored calibration: ±0.05 nm on start/stop, ±2 % on
speed.

---

## `lina_ofdr.py` — aux-referenced OFDR

| Function | Purpose |
|---|---|
| `combine_pair(traces, channels, mode, label)` | Turns a channel pair into one interferogram. Whether it is a balanced pair is decided from the **correlation** (measured −0.88 … −0.99), not assumed. |
| `highpass(sig, rate, cutoff)` | Strips the residual power envelope. Without it the aux "fringe frequency" is estimated as 0.000 kHz and the Hilbert phase is biased. |
| `aux_phase(sig)` | Unwrapped fringe phase — this *is* the optical-frequency axis. |
| `aux_quality(sig, rate)` | Dominant fringe frequency and how single-tone the aux really is. Both are warnings, not decorations: a non-single-tone aux invalidates the phase reference. |
| `resample_on_aux(meas, phase)` | Interpolates the measurement onto a uniform phase grid, and reports what fraction of the phase is non-monotonic. |
| `fft_to_distance(sig, dnu_total_hz, n_group, ...)` | Kaiser-windowed FFT → distance. `dz = c/(factor·n_g·Δν)`. |
| `list_peaks(spec, ...)` | Peaks, reported in both conventions so an axis label cannot mislead. Excludes the region around z = 0, where a subtracted offset leaves the interferometer's own peak (its skirt can outrank the fibre peak). |
| `decimate_max(z, db, n_out)` | Block maximum for display ("peak hold") plus the block median as the true noise floor. |
| `evaluate(...)` | The whole pipeline for one channel pair, referenced to the other. |

### Conventions, and why they differ per channel pair

- The **test fibre** is traversed **twice** (measured: 1 m → 2.079 m of path,
  3 m → 6.051 m), so its axis uses `2·n_g` and subtracts the measurement
  interferometer's own imbalance (0.57396 m) — then it reads fibre length.
- The **aux delay line** is traversed **once** (nominal 4 m reads 4.16 m with
  `n_g`), so it keeps `n_g` and its own axis. Its fibre-dependent peak sits at
  `|own − 2·L|`, which folds once the fibre exceeds half its own imbalance —
  which is why that panel is deliberately not relabelled as a fibre length.

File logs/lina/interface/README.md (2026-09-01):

# Instrument driver: Thorlabs TOF1550

`TunableFilters.py` — driver for the C-band digital tunable bandpass filter
used as the wavelength marker for the λ(t) calibration.

It lives here rather than in the repository's `Interface/` folder so that
`Interface/` stays exactly as it was. **If the filter should become a regular
GUI instrument**, this file belongs in `Interface/`, its configuration in
`Interface/config/`, and the device in the GUI's device registry.

Reasoning and measurements: `../report.md`, §2.

## Specification (User Guide TTN356097-D02)

| Property | Value |
|---|---|
| Tuning range | 1527 – 1567 nm |
| Passband (−3 dB) | 0.21 nm — measured here 0.15–0.23 nm |
| Setting error (absolute) | < 32 pm — measured here ~15 pm at 1550 nm |
| Repeatability | ±8 pm |
| Interface | USB-C, FTDI VCP, 115200 8N1 |

## Two deviations from the manual, found on the unit

1. Replies are **LF**-terminated, not CR as documented.
2. Replies are prose with a prefix: `OK. The center wavelength is 1550.000 nm.`
   The driver therefore extracts the first number from the reply.

## Port

Pinned in `config/TunableFilter_config.json` to **COM6**. It has to be pinned:
the unit enumerates through the generic FTDI VCP driver (VID 0403, "USB Serial
Port"), so it is indistinguishable from any other FTDI adapter, and it has no
identity command. Note that COM17 on this machine is a *Thorlabs TEC
controller* — the Thorlabs USB VID is not a reliable hint.

## Use

```python
from lina.interface.TunableFilters import TOF1550
f = TOF1550('tof1550-1')
f.open()
f.set_wavelength(1550.0)      # nm, returns the read-back value
print(f.get_wavelength())
f.close()
```

Set/read-back was exact to 0 pm at 1545, 1550.5 and 1560 nm. There is no
motion-status query on this instrument, so `set_wavelength` waits a fixed
`settle_s` (1 s by default, from the config) and then verifies by read-back.

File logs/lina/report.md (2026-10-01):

# Lina OFDR — work report, 2026-09-01

Full record of one measurement day on **Lina** (EXFO T200S swept laser +
coreDAQ-1, LINEAR variant): every consideration, every measurement, every
number, every dead end and every correction.

Everything produced that day lives in this folder. The rest of the repository
is unchanged, with two justified exceptions (§10).

**Note on the data:** the raw captures and the figures made from them are
**not kept in git** (~190 MB of measurement data, which does not belong in a
code repository). They remain on the measurement PC under `data/`. Every
number they produced is in this report, and the figures can be regenerated
from the captures with the scripts in `scripts/`. The calibration itself
(`calibrations/`) **is** kept, because the GUI and the scripts depend on it.

---

## Contents

| § | Topic |
|---|---|
| 1 | The original problem, and how it turned out to be a different one |
| 2 | The TOF1550 as a wavelength marker (driver + first measurement) |
| 3 | What the capture really contains — the λ(t) calibration |
| 4 | Two capture bugs that made large captures unusable |
| 5 | Stability: repeatability and drift |
| 6 | OFDR: from a capture to a fibre length |
| 7 | The fibre-length measurements (1mA, 1mB, 3mB, 3mB+1mB, none) |
| 8 | Presentation: convention, offset, axes, noise |
| 9 | What was tested and **rejected** |
| 10 | Changes outside this folder |
| 11 | Open points |

---

## 1. The original problem, and how it turned out to be a different one

**Starting hypothesis (yours):** the EXFO sweeps and triggers coreDAQ-1; the
trigger is not synchronised, so the capture contains *the laser's settling
period, the sweep, and the return to the start wavelength*.

**What held up:** that the wavelength axis was wrong, and that the capture
contains more than the sweep.

**What did not hold up:** the cause. There is no settling period in the
capture. The EXFO does not raise its sync output until it has finished
settling. Proven by control experiment: laser parked at the start wavelength
for 5 s versus not parked at all — the marker moved by **< 1 pm** (5.9067 s
versus 5.9064 s). The dead time is at the **end**.

From that followed the actual finding: the GUI *constructed* the axis wrongly,
it did not trigger wrongly.

---

## 2. The TOF1550 as a wavelength marker

### 2.1 The idea

A narrowband filter in the path transmits only near its centre wavelength. Its
transmission peak therefore marks a **known wavelength at a measurable time**
in the capture. That makes the time → wavelength mapping directly measurable
instead of inferred from setpoints.

### 2.2 Identifying the device

The filter did not exist in software. Finding its port:

| Port | Device | Result |
|---|---|---|
| COM17 | "Thorlabs MTD Series Evaluation Board", VID 1313 | **not** the filter — replied in mK/ms (TEC controller) |
| COM11 / COM12 | STM32 CDC (VID 0483) | the two coreDAQs |
| COM14 | SiLabs CP210x | something else |
| **COM6** | FTDI (VID 0403), "USB Serial Port" | **the TOF1550** |

The first guess, COM17, was wrong — the Thorlabs VID was misleading. The
TOF1550 uses the generic FTDI VCP driver, is **not** identifiable from its USB
descriptor, and has no `*IDN?`. Its port is therefore pinned in configuration.

### 2.3 Protocol (User Guide TTN356097-D02 §4.2) and two deviations from it

115200 8N1, abbreviated SCPI: `WAVElength?`, `WAVElength X` (nm),
`WAVElength:STep` (pm), `:INcrease`, `:DEcrease`, `CHANnel`.

Found on the unit itself, differing from the manual:

1. Replies are **LF**-terminated, not CR as documented.
2. Replies are prose with a prefix: `OK. The center wavelength is 1550.000 nm.`
   → the driver extracts the first number from the reply.

### 2.4 Driver test

| Set | Read back | Error |
|---|---|---|
| 1545.000 nm | 1545.000 nm | 0 pm |
| 1550.500 nm | 1550.500 nm | 0 pm |
| 1560.000 nm | 1560.000 nm | 0 pm |

Step/increase/decrease also verified (100 pm step → 1560.0 → 1560.1 → 1560.0).

### 2.5 Passband measured in CW (ground truth)

Laser stepped in CW in 25 pm steps over 1.5 nm, all four channels:

| Channel | Peak | FWHM | max | baseline | contrast |
|---|---|---|---|---|---|
| Ch1 | 1549.9846 nm | 0.225 nm | 0.70 µW | 1.3 nW | 549× |
| Ch2 | 1549.9981 nm | 0.150 nm | 154 µW | 0.30 µW | 517× |
| Ch3 | 1549.9860 nm | 0.175 nm | 0.60 µW | 0.5 nW | 1173× |
| Ch4 | 1549.9643 nm | 0.175 nm | 151 µW | 0.34 µW | 447× |

FWHM 0.15–0.23 nm against a datasheet 0.21 nm at −3 dB: consistent. Filter set
to 1550.000 nm versus a true peak of ~1549.99 nm → **absolute error ~15 pm**,
inside specification (< 32 pm). So the filter is usable as a marker.

**Side finding:** both strong channels show a **notch right on the peak** —
probably coreDAQ autorange switching at full scale. Irrelevant for the
calibration (the centroid is robust), possibly not for spectra. Unresolved
(§11).

**Correction to myself:** the first channel selection ("best channel Ch3") was
wrong because it chose by *contrast* — an unconnected channel has enormous
contrast on nanowatt noise. Changed to absolute peak power.

---

## 3. What the capture really contains — the λ(t) calibration

### 3.1 Raw capture, one sweep, filter at 1550 nm

1520 → 1570 nm at 5 nm/s, 12.00 s armed window, 10 kHz:

- **one** peak at **5.9065 s**, width 59 ms
- a **second, narrow** peak at **10.1195 s**, width 2.8 ms

Interpretation: the broad peak is the sweep crossing the passband (0.18 nm at
5 nm/s = 36 ms); the narrow one is the laser's **return slew** crossing the
same wavelength 20× faster. This was the first direct sighting of the return
inside the buffer.

The naive linear model puts 1549.986 nm at 5.9972 s → **−91 ms = −454 pm**.

### 3.2 Eight filter positions → λ(t)

1530 … 1565 nm in 5 nm steps, 5 kHz, `--trust-filter`:

| Filter | Time in the buffer | Peak width |
|---|---|---|
| 1530 nm | 1.9622 s | 60.5 ms |
| 1535 nm | 2.9455 s | 61.4 ms |
| 1540 nm | 3.9314 s | 60.4 ms |
| 1545 nm | 4.9185 s | 58.4 ms |
| 1550 nm | 5.9064 s | 60.8 ms |
| 1555 nm | 6.8990 s | 60.2 ms |
| 1560 nm | 7.8934 s | 61.6 ms |
| 1565 nm | 8.8909 s | 60.4 ms |

### 3.3 Fit degree: why quadratic

| Degree | Residual |
|---|---|
| 1 (linear) | **27.2 pm rms**, 43.9 pm max |
| **2** | **3.1 pm rms**, 5.1 pm max |
| 3 | 1.9 pm rms, 3.9 pm max |
| 4 | 1.9 pm rms, 3.7 pm max |

Degree 1 leaves a **systematic arch** (−39, −6, +13, +26, **+35**, +20, −4,
−44 pm) — not noise, real curvature. Degree 2 removes it, degree 3 adds
nothing. So **degree 2**.

### 3.4 What the fit says about the laser

| Quantity | Value |
|---|---|
| effective sweep rate (t=0) | **5.1174 nm/s** versus 5.0000 commanded (+2.3 %) |
| trigger dead time | **+0.0041 s** — essentially zero |
| sweep ends at | **9.8895 s** of 12.00 s |
| sweep occupies | **82.4 %** of the armed buffer |

So the sweep starts at the trigger edge and finishes 0.13 s before its nominal
end because it runs too fast. The remaining 2.1 s are tail, including the
return slew.

### 3.5 What that cost the old evaluation

Same 100 kHz capture, marker demonstrably at 1550.000 nm:

| Axis construction | Marker appears at | Error |
|---|---|---|
| linspace over the whole buffer | 1544.612 nm | **−5.4 nm** |
| + `Buffer time` 1 s | 1542.304 nm | −7.7 nm |
| + `Buffer time` 2 s (your default) | 1539.534 nm | **−10.5 nm** |
| + `Buffer time` 3 s | 1536.149 nm | −13.9 nm |
| **measured λ(t), degree 2** | **1549.997 nm** | **−3 pm** |

Three separate error sources:

1. **Axis stretched over the whole buffer** instead of the 9.89 s sweep —
   dominant, −5.4 nm.
2. **`Buffer time` crops at the front** — corrects the wrong end, deletes real
   1520–1530 nm data and makes the error monotonically worse.
3. **Commanded versus actual sweep speed** — 1–2 %, ~0.5 nm over 50 nm,
   remains even after 1 and 2 are fixed.

### 3.6 Rate independence (the decisive test)

The fit is in **seconds**, not samples. Calibration measured at **5 kHz**,
applied to a **100 kHz** capture of 1.2 M samples: marker at **1549.9970 nm**,
i.e. **−3 pm**. So: calibrate once at a low, reliably readable rate and apply
it at the production rate.

---

## 4. Two capture bugs that made large captures unusable

### 4.1 Read too early (deterministic, this was the main cause)

A LINEAR capture free-runs `n_frames / rate` seconds **from the trigger edge**
— independent of how long `start_continuous_sweep()` blocks. With 1.2 M frames
at 100 kHz = **12.00 s** window against a **10.81 s** sweep, the buffer was
still filling when it was read. The USB transfer then stalls (the remaining
frames do not exist yet), the transport's 30 s budget expires, and
py_coreDAQ's reset-retry **destroys the arming** → the follow-on error "no
capture was armed by this session".

Observed: stalls at 4,234,228 / 4,800,000 bytes (88 %) and at
424,308 / 480,000 (88 %).

**Fix:** wait out the armed window before reading. After that, 1.05 M and
1.2 M frames read cleanly.

### 4.2 Sporadic packet loss (statistical, still present)

Even with a full buffer the read occasionally dies, and always exactly
**512 bytes** short of the end — the USB packet size. Exactly one packet is
lost.

**Rejected hypothesis:** that this is an alignment effect (byte count an exact
multiple of 512). I declared it confirmed after *one* success and *one*
failure — too early. The control experiment refuted it:

| Frames | Bytes | % 512 | Result |
|---|---|---|---|
| 1,200,000 × 2 ch | 4,800,000 | 0 | stalled at 4,799,488 |
| 1,199,999 × 2 ch | 4,799,996 | 508 | first **succeeded**, two minutes later **stalled** at 4,799,484 |

Same frame count, both outcomes. So **no** alignment effect; the workaround
that had been added was removed again.

Measured failure rate:

| Transfer | Channels × frames | Failures |
|---|---|---|
| 4.8 MB | 2 × 1.2 M | 3 of 6 attempts |
| 8.4 MB | 4 × 1.05 M | both runs affected, one exhausted 2 retries |

**Fix:** the whole park → arm → sweep → read sequence is repeated as a unit (a
failed read consumes the arming, so re-reading is impossible). Budget: 4
attempts. Plus a 5 s wait before retrying: after an aborted sweep the EXFO
stays `busy` for a few seconds and rejects the trigger reconfiguration with
`Metrino.T200S.BusyException` — with a 1 s wait the retry was burned on the
laser instead of on the failure being retried.

Verified: 3 runs of 1.2 M × 2 ch → one failed twice and succeeded on the third
attempt, one failed once, one succeeded immediately — **all three ended with
usable data**.

### 4.3 Side observation

The coreDAQ can wedge such that the port no longer opens
(`PermissionError: Access is denied`) and only a physical replug helps. I first
attributed this to two leftover Python processes — wrong: they were still
running long after the port worked again.

---

## 5. Stability: repeatability and drift

Filter fixed at 1550 nm, identical sweeps:

| Test | Runs | Span | Scatter | Drift |
|---|---|---|---|---|
| short | 5 | 1.7 min | 0.8 pm rms, 2.0 pm p-p | −0.9 pm/min (not resolvable) |
| long | 6 | 18.0 min | **0.7 pm rms**, 1.7 pm p-p | **+0.0 pm/min** |

The scatter does **not** grow over the 10× longer span → white noise at the
level of the fit residuals, no time-dependent component.

**Consequence: one calibration per sweep configuration is enough.** No
re-calibration during a session.

---

## 6. OFDR: from a capture to a fibre length

### 6.1 Setup

- **Ch1, Ch3** — measurement MZI, contains the test fibre
- **Ch2, Ch4** — reference MZI ("aux"), ΔL nominally 4 m

Each MZI is read on two channels. Whether a pair is balanced is decided from
its **correlation**, not assumed: measured −0.88 to −0.99 → balanced
difference.

### 6.2 Why the aux MZI is needed

The coreDAQ samples uniformly in **time**; the FFT needs uniformity in
**optical frequency**. The aux MZI has a fixed delay, so its fringe phase is
strictly proportional to optical frequency: `φ(t) = 2π·τ_aux·ν(t)`. Resampling
the measurement onto a uniform φ grid makes it uniform in ν.

**Independent confirmation of the calibration:** the unwrapped aux phase
deviates from a straight line by **1.08 % of the frequency span** — as a
smooth arch, i.e. the same quadratic nonlinearity the filter fit found as its
degree-2 term. Two entirely different methods, same result.

### 6.3 Scale

```
dz    = c / (factor · n_g · Δν)          resolution
z_max = dz · N/2 = c·f_s / (2·factor·n_g·dν/dt)
```

With 1520–1570 nm: Δν = 6.2813 THz, n_g = 1.4682 → dz = 16.3 µm (reflection
convention), Nyquist 8.03 m. Δν comes from the **calibrated** wavelength axis,
not the commanded range — otherwise the 1–2 % speed error would go straight
into every length.

### 6.4 Validation on synthetic data

Known 1.000 m path imbalance, 5 m aux, deliberately nonlinear sweep, noise:
**1.00000 m** recovered (error < 0.01 mm), plus a planted −28 dB secondary
reflection at 2.5 m found. Implied aux length 5.048 m against 5.000 m true.

### 6.5 High-pass before the phase extraction

Balanced subtraction does not fully remove the power envelope (unequal
detector responsivity). The remainder dominates the spectrum at DC: the aux
"fringe frequency" was estimated as **0.000 kHz**, i.e. useless. With a 500 Hz
high-pass it jumped to 11.1 kHz. Fringes are at kHz, the envelope at Hz — they
separate cleanly.

---

## 7. The fibre-length measurements

### 7.1 First assignment (before the signs were known)

Both channel pairs, each using the *other* as reference — two independent
measurements that check each other:

| Pair | Peak | Expected from that pair's fringe frequency |
|---|---|---|
| Ch1/Ch3 | 1.14795 m | 1.148 m (3.57 kHz) ✓ |
| Ch2/Ch4 | 4.16179 m | 4.16 m (12.95 kHz) ✓ |

Repeatability over 3 sweeps: 1.14795 / 1.14800 / 1.14797 m → **±0.03 mm**.

### 7.2 The fibre swap as an experiment

1mB → 1mA swapped:

| Pair | Peak | 1mB | 1mA | Shift |
|---|---|---|---|---|
| meas | main | 1.14797 | 1.14793 | −0.05 mm |
| meas | | 1.01266 | 1.01273 | +0.07 mm |
| meas | | 1.04986 | 1.04992 | +0.07 mm |
| meas | | **3.22729** | **3.25856** | **+31.26 mm** |
| aux | | **2.08219** | **2.05117** | **−31.02 mm** |
| aux | main | 4.16197 | 4.16196 | −0.01 mm |

Two peaks move by the same amount with **opposite sign**. The strong peaks do
**not** move — so they are not the fibre.

### 7.3 Measurement with no fibre (this settled the assignment)

| Peak | 1mB | 1mA | no fibre | Interpretation |
|---|---|---|---|---|
| 1.0127 m | −24.9 | −25.6 | −31.0 | fibre-independent |
| 1.0499 m | −24.8 | −26.2 | −31.2 | fibre-independent |
| **1.1480 m** | 0.0 | 0.0 | 0.0 | measurement MZI's own ΔL |
| 3.2273 / 3.2586 m | −22.4 | −18.4 | **gone** | **only with a fibre** |
| 2.0822 / 2.0512 m (aux) | −10.0 | −7.9 | **gone** | **only with a fibre** |
| **4.1620 m** (aux) | 0.0 | 0.0 | 0.0 | aux MZI's own ΔL |

Exactly two peaks vanish without a fibre. The strongest peak is **not** the
fibre — that was the most important misinterpretation this measurement ruled
out.

### 7.4 Model and its self-check

```
measurement pair peak = 1.1480 m + L        (test fibre traversed TWICE)
aux pair peak         = |4.1620 m − L|      (aux traversed ONCE)
```

| | L from the meas pair | aux peak predicted | aux peak measured | Deviation |
|---|---|---|---|---|
| 1mB | 2.0793 m | 2.08265 m | 2.08219 m | 0.46 mm |
| 1mA | 2.1106 m | 2.05133 m | 2.05117 m | 0.16 mm |

The cross-sum must be constant (1.1480 + 4.1620 = 5.3099 m): measured 5.30948
(1mB) and 5.30973 (1mA) → both within **0.5 mm**, with one free parameter.

The factor of 2 was confirmed by the 3 m fibre: 1 m → 2.079 m of path,
3 m → 6.051 m. And the aux ΔL of nominally 4 m reads **4.162 m** with factor
n_g → traversed once. (If it were exactly 4.000 m, n_g would have to be 1.528
— unrealistic for SMF-28, so it really is ~4.16 m.)

### 7.5 Final results (axis reads fibre length)

| Fibre | Peak | Prediction | dB |
|---|---|---|---|
| **1mB** | **1.0397 m** | — | −22.4 |
| **1mA** | **1.0553 m** | — | −18.4 |
| **3mB** | **3.0256 m** | — | −31.2 |
| **3mB + 1mB** | **4.06334 m** | 3.02564 + 1.03969 = 4.06533 | −31.9 |
| no fibre | no peak | — | — |

**The lengths add up to within 2.0 mm (0.05 %).** That confirms the scale
independently from 1 m to 4 m with no re-adjustment. The prediction made before
the measurement was 4.065 m — hit to 1.9 mm.

1mA is **15.6 mm longer** than 1mB.

Other real signals: at 1.51 m half the 3 m fibre (multiple reflection); at
3.03 m, in the series connection, the connector between the two fibres; a broad
bump at 2.5–2.7 m (distributed scatter, not a point reflection — its median is
raised too).

---

## 8. Presentation

### 8.1 Convention (changed twice, as the physics became clear)

| Stage | Factor | A 1 m fibre appears at |
|---|---|---|
| initially | 2·n_g | 0.5 m |
| after your request "1 m should be at 1 m" | n_g | 1.0 m — but only coincidentally right |
| **final, once the double pass was proven** | 2·n_g **+ offset subtraction** | 1.0397 m, physically correct |

The two panels need **different** conventions, because the test fibre is
traversed twice and the aux delay line once.

### 8.2 Offset subtraction, and why the aux panel gets no fibre-length axis

`--offset-m 0.57396` subtracts the measurement MZI's own ΔL → the axis reads
fibre length. The equivalent for the aux panel would be a **mirror** about
2.08098 m — but that **folds** as soon as the fibre exceeds half the aux ΔL:
for the 3 m fibre, \|4.162 − 6.051\| is negative, the peak folds, and the
mirrored axis wrongly showed 1.136 m instead of 3.026 m. The aux panel
therefore keeps its own axis.

### 8.3 Noise display

The problem was not the scaling (dB is already logarithmic) but that ~2 M FFT
bins are drawn and the noise fills in as a solid block. Solution: **block-maximum
decimation** ("peak hold", 3000 points) — peaks keep their exact height (a peak
*is* the maximum of its block) and the noise collapses to a thin line. Plus the
block median as a grey area = the actual noise floor.

### 8.4 Axis windows

`auto` frames the detected peaks (±0.2 m, minimum 0.6 m span) instead of the
whole Nyquist range.

---

## 9. What was tested and rejected

This section is deliberately complete — rejected ideas are results.

| Idea | Test | Outcome |
|---|---|---|
| The trigger captures the settling phase | 5 s park versus no park | **refuted**, < 1 pm difference |
| `Buffer time` (front crop) fixes the axis | marker of known wavelength | **refuted**, makes it monotonically worse (−5.4 → −13.9 nm) |
| 512-byte alignment causes the read stall | non-aligned byte count | **refuted**, fails identically; workaround removed |
| Leftover Python processes blocked COM12 | processes still running while the port worked | **refuted**, the device had wedged |
| Pick "best channel" by contrast | an unconnected channel wins | **wrong**, changed to peak power |
| The first 10 nm are bad and must be excluded | fringe amplitude per 0.5 nm; crop scan 0/2/5/10/15/20 nm — **both on script captures only** | **wrong conclusion, see §9.2.** True for GUI captures, and the cause was fixable |
| Degree 3 or 4 for λ(t) | residuals | **no gain** over degree 2 |

### 9.1 The crop scan in detail

| Crop | Samples | dz | Peak | Shift | SNR | FWHM |
|---|---|---|---|---|---|---|
| 0 nm | 988,536 | 16.25 µm | 4.06334 m | — | 41.8 dB | 0.05 mm |
| 2 nm | 949,435 | 16.95 µm | 4.06415 m | +0.81 mm | 41.9 dB | 0.06 mm |
| 5 nm | 890,717 | 18.12 µm | 4.06435 m | +1.01 mm | 41.7 dB | 0.05 mm |
| 10 nm | 792,672 | 20.45 µm | 4.06520 m | +1.86 mm | 40.6 dB | 0.05 mm |
| 15 nm | 694,401 | 23.45 µm | 4.06530 m | +1.96 mm | 41.3 dB | 0.09 mm |
| 20 nm | 595,900 | 27.45 µm | 4.06591 m | +2.57 mm | 42.2 dB | 0.08 mm |

SNR stays at 41–42 dB, and FWHM gets worse at heavy crops (dz grows as Δν
shrinks). The fringe amplitude is constant across the whole sweep (0.78–1.05 ×
median in the aux, 0.96–1.03 in the measurement channel, nothing below 60 %).

**One side finding remains:** the peak moves systematically by up to +2.6 mm.
That is not a length change but the peak's own structure (2–3 sub-lobes over
~50 mm) with the maximum jumping between them. So the **systematic**
uncertainty is ~±2 mm while the **repeatability** is ±0.03 mm. Irrelevant for
comparisons, relevant for absolute values.

### 9.2 Correction: the first 10 nm *were* bad — in GUI captures

You asked whether the first 10 nm looked bad and whether I had excluded them.
I checked, found nothing, and said so. That answer was wrong, because I only
ever checked **script** captures, where the first 10 nm are clean. The
difference only appeared when GUI and script captures taken one minute apart
were compared block by block:

| Block | GUI fringes | script fringes | ratio | GUI aux amplitude |
|---|---|---|---|---|
| 0–1 s | 8,224 | 13,450 | **0.61** | 0.134 |
| 1–2 s | 10,234 | 13,339 | **0.77** | 0.153 |
| 2–3 s | 13,412 | 13,237 | 1.01 | 0.187 |
| 3 s onwards | … | … | 1.01–1.02 | 0.19–0.21 |

In GUI captures the first **2 s = the first 10 nm** carry ~25 % less fringe
amplitude and 23–39 % fewer fringes; from 2 s on the two paths agree to 1.5 %.

**Cause:** the script parks the laser at the start wavelength and waits 5 s
**before arming**; the GUI parked only after arming and did not wait. So the
laser's start-of-sweep transient was being captured.

**Consequence:** the corrupted first 2 s spoiled the aux phase, which cost 5 %
of the total fringe count and therefore stretched the distance axis by 5 % —
this is exactly what made the OFDR button report 2.846 m for a 3.026 m fibre
(§11.1, now fixed).

**Why my earlier control experiment missed it:** that test compared the
*position* of a wavelength marker with and without parking, and position is
genuinely unaffected (< 1 pm). Signal *quality* at the start of the sweep is
not, and I had not measured it. Both statements in §1 and §3.4 about timing
stand; the claim that parking "makes no difference" was too broad.

**It also retroactively vindicates `Settle margin`** (§10.1): there really is a
start-of-sweep transient. Parking and settling before arming addresses it at
its source and, unlike the margin, costs no sweep range and leaves the
calibration valid.

---

## 10. Changes outside this folder

Everything new lives in `lina/`. Two existing files had to change because you
wanted the functionality in the GUI:

### 10.1 `LabGUI/dashboards/instruments/lina_window.py`

| Change | Reason |
|---|---|
| "Use λ(t) calibration" (default on) + status line | shows **before** a sweep whether a calibration exists for Start/Stop/Speed |
| λ(t) axis + tail cropping in `_CoreDAQSweepWorker` | §3 |
| **`Buffer time` removed entirely** (field, front crop, arming arithmetic) | §3.5 — its premise was refuted |
| `Settle margin` kept, default 10 → **0 nm** | two reasons, both verified: (a) a non-zero value shifts the physical sweep start, so the calibration no longer matches and is silently skipped — back to the −5.4 nm linear axis; (b) the start-of-sweep transient it was compensating is now removed at its source by parking and settling before arming (§9.2). No clipping in the first 10 nm either (§11.3). |
| wait for the armed window | §4.1 |
| **park at the start wavelength and settle 5 s BEFORE arming** (`PARK_SETTLE_S`) | §9.2 — without it the first 10 nm of every GUI capture are degraded and the OFDR distance axis comes out 5 % short |
| capture retry (4 attempts, 5 s pause) | §4.2 |
| Samples/ch default 1,000,000 → 1,050,000, auto-fit on parameter change | matches sweep + 5 % head room, no more ⚠ warning |
| all four coreDAQ channels by default | OFDR needs both MZI pairs from the **same** sweep |
| "restore λ" default on | matches the scripted measurement runs |
| button **"OFDR Plot"** + n_g / MZI-offset fields | the two spectra from the last capture |

### 10.2 `Interface/PowerMeters.py`

| Change | Reason |
|---|---|
| `arm_sweep_capture` returns the armed frame count | the GUI needs the value actually armed |
| `read_sweep_capture` clamps to the armed count | avoids a misleading validation error on FW v4.2, where `captured_frames()` returns −1 |
| docstring documents the 512-byte packet loss | §4.2 |

**Reverted:** `.gitignore` and `CAROLINA_OFDR_CHANGES.md` are back to their
pre-today state (`519e18f`).

**The TOF1550 driver lives in `lina/interface/`**, not `Interface/`, so that
`Interface/` stays unchanged. If the filter should become a regular GUI
instrument type, it belongs in `Interface/` and in the device registry — its
configuration would then move to `Interface/config/` as well.

---

## 11. Open points

1. ~~**The GUI button does not yet give the right length.**~~ **RESOLVED.**
   The symptom was an aux phase with ~5 % too few fringes in GUI captures
   (121,212 against 128,015 in a script capture one minute later), stretching
   the distance axis by the same factor: 2.846 m for a 3.026 m fibre. The cause
   was the missing park-and-settle before arming (§9.2), which left the first
   2 s of every capture degraded. After moving the park before the arming, the
   button reports **3.0256 m** with **128,011** aux fringes — matching the
   script's 3.02551–3.02568 m and 128,015 fringes.

   Two bugs in my own code were found on the way there: the reference channel
   pair was passed the string `"aux"` in `combine_pair`'s *mode* parameter, so
   it was silently not balanced-subtracted; and the "strongest peak" report
   picked the skirt of the interferometer's own peak at z ≈ 0 (−31 dB) over the
   fibre peak (−31.7 dB), which is why the status line said −0.03 m. Both
   fixed; `list_peaks` now excludes the near-zero region when an offset has
   been subtracted.
2. **Autorange notch** on strong peaks (§2.5) — probably TIA range switching.
   Testable with a fixed range instead of autorange.
3. ~~**`Settle margin`** — the saturation in the first ~10 nm was never
   cross-checked.~~ **CHECKED, and there is none** in the current optical
   configuration: across two captures (with and without the park-and-settle),
   **0.00 %** of samples sit at full scale in any wavelength range, and the
   peak-to-peak in 1520–1530 nm (0.44–0.47 mW) is normal against 0.47–0.52 mW
   at the end of the sweep — that difference is the fringe amplitude growing
   across the sweep, not saturation.

   Note what the 10 nm the margin defaulted to actually corresponded to: the
   degradation found in §9.2 was **exactly 10 nm wide** (2 s at 5 nm/s), so the
   value had been chosen correctly for a real effect. Parking and settling
   before arming prevents that effect instead of skipping over it, which costs
   no sweep range and keeps the calibration valid — hence the default of 0.

   **Caveat:** the margin's original justification came from a different
   optical configuration (laser straight into the coreDAQ, no EDFA or VOA in
   the path). If that configuration returns, saturation could too. The order
   to follow then: measure with margin 0 and look for clipping; if it clips,
   fix the level or the range, or use the margin **and** calibrate that
   configuration — the calibration has to match the physical sweep, which with
   a 10 nm margin starts at 1510 nm, not 1520 nm.
4. **Absolute scale** depends linearly on n_g = 1.4682. The differences are
   sound; absolute values would need a fibre of known length or an OSA
   comparison. Calibrating with `--trust-filter` also means: relative accuracy
   ~3–5 pm, absolute ±32 pm (the filter's specification).
5. **The calibration is valid only for 1520–1570 nm at 5 nm/s.** Any other
   configuration needs a ~3-minute run; the lookup deliberately refuses a
   mismatched calibration.
6. **Large reads remain statistically unreliable** (§4.2). At four channels,
   8.4 MB often fails; the retry absorbs it but costs one sweep each time.

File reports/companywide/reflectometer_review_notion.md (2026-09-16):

# The OFDR reflectometer — how I built it, what I measured, what I still don't know

Carolina Krotsch · 16 September 2026

This is a general write-up for the company. First how the setup works, then how a raw scan turns into a length, then everything I have measured so far (fibres and chips) with the results, and at the end the list of things I don't understand and would like help with.

---

## 1. What the instrument is

It's an **optical frequency-domain reflectometer (OFDR)** — basically a home-built version of a Luna OBR. You sweep a tunable laser in wavelength, mix the light coming back from the device under test with a reference copy of the same light, record the interference, and Fourier-transform it. Every reflecting interface along the fibre then shows up as one peak, at its own distance.

Why that works: with the laser at optical frequency ν, a reflector sitting at round-trip delay τᵢ gives

```
I(ν) = Σᵢ 2·√(P_LO·Pᵢ)·cos(2π·τᵢ·ν + φᵢ)
```

So if you look at the signal as a function of ν, it's just a sum of sine waves — one per reflector — and the frequency of each sine wave *is* its delay. That's why an FFT over ν gives you the reflectogram directly.

Two numbers describe what the instrument can do:

| quantity | formula | what I have |
| --- | --- | --- |
| resolution | Δz = c / (2·n_g·Δν) | **16.3 µm** at 1520–1570 nm, **6.9 µm** at 1505–1625 nm |
| max. distance | z_max = c / (4·n_g·δν) | **8.0 m** at 1520–1570 nm, **3.4 m** at 1505–1625 nm |

with n_g = 1.468 for SMF-28 at 1550 nm. Note that resolution and range trade off against each other: range/resolution = N/2, where N is the number of points. So a wider sweep gives better resolution but less range. How *fast* you sweep doesn't matter for either.

### 1.1 The hardware

- **Laser:** EXFO tunable, 1505–1625 nm, swept at 10 nm/s.
- **Detector:** CoreDAQ multichannel power meter (dev unit), 4 channels, running free on its own internal clock. A normal scan is **988,536 points** over 1520–1570 nm, which is about 150 MB of JSON.
- **Measurement interferometer:** built around a circulator, so I reach the device in reflection. The device under test hangs on a ~1 m patchcord.
- **Auxiliary interferometer ("the ruler"):** a Mach–Zehnder with ΔL ≈ 4.2 m, made from two ~2.07 m fibres. This is the part that makes everything work — see section 2.
- **Which channel is which:** Ch2/Ch4 = aux (the strong pair), Ch1/Ch3 = measurement (the weak pair). The pairs are interleaved, not next to each other. I got this wrong for two weeks; it was settled by checking the wiring by hand on 31 August.
- Everything the instrument owns was rebuilt in **PM fibre** in September. The device arm stays SM because that's what the chips have. All connectors FC/APC.

### 1.2 The one decision that changed everything

At the start I sampled on the laser's own trigger output, one trigger per 1 pm. That limits the range to **0.42 m** — shorter than my own patchcord. So the far end of the test fibre was outside the range and folded back into the middle of the trace as an ugly smeared band at about −40 dB. I tested and killed four different explanations for that band before a simulation showed it was simply aliasing. Once something aliases there is no software fix, because the information is already gone at the sampling stage.

The fix was to **stop using triggers and sample free-running**, like a Luna does. That gives about 20× more range at better resolution. The catch is that without triggers there is *no wavelength information at all* in the data — and that's exactly what the auxiliary interferometer provides.

---

## 2. How a raw JSON scan becomes a length

This is the part worth understanding, because every number further down comes out of it. The script is `process_reflectogram_aux.py`.

**What I start with.** A JSON file with four arrays in mW, one sample per clock tick, and no wavelength axis at all:

```json
{"data": [{"Ch1 [mW]": [...], "Ch2 [mW]": [...],
           "Ch3 [mW]": [...], "Ch4 [mW]": [...]}]}
```

**Step 1 — balanced subtraction.** The two channels of each pair are the two complementary outputs of the same coupler, so P = Ch_a − g·Ch_b cancels the DC offset and the common-mode intensity noise. g is fitted piecewise because the two photodiodes don't have the same responsivity slope — it drifts from about 0.84 to 1.14 across the sweep. Done separately for the aux pair and the measurement pair.

**Step 2 — get the frequency axis back from the aux.** The aux is a fixed delay τ_aux, so its phase is

```
φ(t) = 2π · τ_aux · ν(t) + const
```

I take the Hilbert transform of the balanced aux signal and unwrap the phase. Then: **equal steps in φ are equal steps in ν.** It doesn't matter how uneven or jittery the laser sweep actually was — the aux measures it. That's the whole trick.

**Step 3 — resample.** I interpolate the measurement signal (PCHIP) onto a uniform φ grid. Now it's evenly spaced in optical frequency and the FFT is allowed. Important: I do **not** smooth the aux phase. It has to follow the laser's fast jitter, otherwise it can't correct it.

**Step 4 — the scale factor.** τ_aux is what converts phase into frequency. I get it by counting fringes over a sweep whose span I know:

```
τ_aux = (total unwrapped aux phase) / (2π · frequency span of the sweep)
```

Right now it's about **20.61 ns** (ΔL ≈ 4.21 m). It has to be redone every time the aux arm gets re-plugged. From it:

```
δν      = Δφ / (2π · τ_aux)         spacing in optical frequency
span_ν  = Δφ_total / (2π · τ_aux)   total span
```

**Step 5 — window and FFT.** Subtract a 5th-order polynomial baseline, apply a Kaiser β = 12 window, then a real FFT. Kaiser because its sidelobes are below −80 dB. Hann gives a sharper peak, but its −31 dB sidelobes look like reflectors when they sit next to a strong peak, and I'd rather not fool myself.

**Step 6 — the distance axis.** FFT bin k sits at

```
z_k = k · c / (2 · n_g · δν · m)
```

with m the number of resampled points. I use the **reflection convention**, z = c·τ/(2·n_g), so z is the one-way distance to the reflector, not the round trip.

**What comes out** is a peak list in mm with amplitudes in dB relative to the strongest peak, plus a CSV and PNG of the whole reflectogram. A worked example for a standard scan:

| quantity | value |
| --- | --- |
| N = 988,536 points, 1520.000 → 1570.000 nm | mean step 0.0506 pm |
| δν | 6.08 … 6.64 MHz (9 % chirp over the sweep) |
| Δν | 6.281 THz |
| resolution Δz = c/(2 n_g Δν) | **16.26 µm** per bin |
| …times the Kaiser factor 2.6 | **≈ 42 µm** actual −3 dB width |
| Nyquist range | **8.03 m** |
| dynamic range I actually get | 63 … 72 dB |

Two checks run automatically on every scan, and I quote them whenever someone doubts a number: the **−3 dB width of the main peak** compared to the window limit (if the frequency axis went wrong, this is where you see it first), and the **minimum aux contrast** (if the aux fades due to polarisation, its phase — and therefore every position — is unreliable).

**For lengths on a chip** there's one more step. The instrument measures delay and reports it in *fibre-equivalent* mm. A waveguide of length s on the chip appears at

```
dz = s · n_g,chip / n_g,fibre
```

So to get s I need the chip's group index. Not having that number is the main problem in all the chip work (sections 4.2 and 5).

---

## 3. Results — fibres

### 3.1 Do the lengths add up?

> 📈 **PLOT — insert `fiber_length_series_august.png` here**

Each trace is one scan, all shifted so their own connector peak sits at x = 0. Grey = nothing connected (control), red = a ~1 m fibre, blue = a ~3 m fibre, purple = the 3 m and the 1 m fibre connected in series.

What you can see:

- Each fibre gives **one clean end reflection**, about 30 dB above everything around it, and the control trace has nothing there.
- The four different "1 m" fibres land at 1002–1019 mm, so they really are different fibres and the instrument can tell them apart.
- The series combination lands at **3939.3 mm**, against 2923.9 + 1015.7 = 3939.6 mm predicted from the same two fibres measured separately. So the instrument **adds up correctly**.

One caveat: this series is from the end of August, and back then the fringe counting for τ_aux had a scale error of roughly 10–15 % that I never fully explained. This plot is the version where the aux length was set to its nominal value instead, which is why the numbers look so round. The *additivity* result doesn't depend on the scale being right, which is why I still like the plot. The current setup is verified much better — next section.

### 3.2 Three 2.07 m PM fibres — the best accuracy test I have

Three nominally identical 2.07 m PM fibres (a, b, c). Two of them always sit in the aux and the third is the device under test, so measuring all three means swapping them around. That turns into a free consistency check, because the aux length enters differently each time.

| fibre | length from the connector plane | vs. 2070 mm from the tape measure |
| --- | --- | --- |
| a | **2085.93 mm** | +15.93 mm |
| b | **2093.89 mm** | +23.89 mm |
| c | **2095.35 mm** | +25.35 mm |

The extra couple of cm is the connector bodies, which you don't include when you lay the bare fibre next to a tape measure.

Because I have three scans for fewer unknowns, two things fall out:

1. **The aux has 23.7 ± 0.1 mm of extra fixed path** on top of the two fibres in it — coupler pigtails and connector bodies. Three independent estimates, one per scan, agree to 0.19 mm. I had assumed the aux was just the two fibres, and that was wrong by 24 mm.
2. **The pair test closes to one resolution cell.** If the aux holds the two fibres that are *not* being measured, then `aux_a − aux_b` has to equal `L(b) − L(a)`. The left side comes from fringe counting, the right side from peak positions, and nothing in the analysis links them. Measured: **+7.943 mm vs +7.960 mm — 17 µm apart.**

That 17 µm is my honest accuracy statement for the instrument on a 2 m path: about **8 ppm**, and limited by the resolution cell rather than by the calibration.

### 3.3 Something I can't explain: every fibre end is a doublet

All three fibre ends show up as **two peaks**, not one, separated by 5.26 / 3.18 / 3.76 mm. The separation is different for each fibre, so it's not a fixed instrument artifact. And the stronger of the two isn't always the end: for fibres a and b the first peak is stronger, for c the second one. So "just take the strongest peak" gives the wrong length for fibre c.

I'm confident the *first* peak is the fibre end, because that assignment makes the three estimates of the aux extra path agree to 0.19 mm while the other one leaves 3.58 mm of scatter. But what the second peak actually *is*, I don't know. See section 5.

---

## 4. Results — chips

### 4.1 Everything on one axis

> 📈 **PLOT — insert `overview_all_scans_from_connector_plane.png` here**

One row per scan, all on the same distance axis with zero at the connector plane, each row normalised to its own strongest peak. The grey underneath each row is the control scan with nothing connected, so anything sticking out above the grey is real.

From top to bottom:

- **Rows 1–3, blue — the Ligentec SiN chip through its fibre array.** One big peak at ~1023–1026 mm, which is the chip input facet. Behind it, nothing above the noise for the next 1.5 m.
- **Rows 4–6, orange — the three bare 2.07 m PM fibres.** A single sharp end reflection at ~2086–2095 mm and a flat floor everywhere else. This is what a clean measurement looks like.
- **Rows 7–14, green — bare fibre arrays with no chip on them** (Meisu and PHIX). Array facet at ~1067–1076 mm, again one peak and nothing behind it.

The reason for putting them all on one axis is the comparison between the blue rows and the green rows: **the chip scans look the same as the scans with no chip at all.** Whatever the chip adds, I can't see it.

The small peak at ~1550 mm in every row is the aux ghost. It's an artifact of the aux itself, sits at ΔL/2, and is there in every scan including the ones with nothing connected. It moves when the aux gets re-plugged while real reflectors don't — that's how I identify it.

### 4.2 The HHI InP chip — the one chip where I got real geometry out

This is the chip measurement that worked. The structure is a **loopback**: two neighbouring edge couplers connected to each other by a short waveguide loop on the chip, and both are permanently pigtailed with ~1 m fibres.

> 📈 **PLOT — insert `hhi_loopback_chain_single_scan.png` here**

Row 1 is what's physically there: reflectometer → fibre 1 → through the chip → fibre 2 → open fibre end, and that open end is what reflects back. Row 2 is the same thing as measured — four peaks in a row, with the coloured stretches in between being the two fibres. Row 3 zooms in on the chip, which is **7.2 mm out of a 2.2 m path**.

| station | z | section in front of it |
| --- | --- | --- |
| internal reference reflection | 573.93 mm | — |
| chip facet A | 1670.23 mm | fibre 1 = **1096.30 mm** |
| chip facet B | 1677.43 mm | **chip = 7.200 mm** |
| open end of fibre 2 | 2773.62 mm | fibre 2 = **1096.20 mm** |

The bit I like most: fibre 1 and fibre 2 are found **completely independently of each other** and come out 1096.298 and 1096.199 mm, so the same to 0.099 mm. Nothing in the analysis forces that, so it tells me all four stations are correctly identified.

> 📈 **PLOT — insert `hhi_loops_measured_explained.png` here**

Same measurement, but for **both** loopback pairs on the chip (design lengths 640.1 µm and 556.5 µm). Row 3 has the design model drawn on top, row 4 shows how far each measured peak lands from where the design says it should be.

Row 3 also carries an important warning: **the loop edges are not in the data.** The waveguide goes smoothly into the spot-size converter, so its ends don't reflect. The only two things the instrument knows about this chip are facet A and facet B — the hatched bars are model, not measurement. And the dips in the curve are window sidelobes plus noise, not structure.

**What this gives me, and what it doesn't.** The reflectometer measures delay, so to turn 7.200 mm into a length I need the chip's group index. It's in none of the documents I have — not the Jeppix validation report (that one has waveguide loss 1.8 dB/cm, butt-joint loss 1.2 dB, SSC coupling loss 1.5 dB typ., but no index), not the device mapping, not the pin mapping — and I don't have the HHI PDK.

So I did the obvious thing and fitted n_g so that the two known design lengths come out right: **n_g = 3.4803 ± 0.008**. I want to flag clearly that **this is circular.** If I fit n_g so that both loops come out right, then of course both loops come out right. I nearly reported it as a result.

What is genuinely *not* circular:

- **The ratio test.** Two loops, one n_g, so one degree of freedom is left over. The measured ratio of the two chip paths is 1.026008 and the design ratio is 1.028268 — they agree to **0.22 %**, against a resolution limit of 0.47 % on that ratio. If the geometry or my peak identification were wrong, this wouldn't close.
- **Both loops reproduce their design path** to within one and two resolution cells (one cell = 7.0 µm on the chip). That's row 4 of the plot.

So what I can defend is: *the measurement agrees with the design geometry at the resolution limit, and the instrument resolves about 7 µm of on-chip waveguide.* What I can't defend is an absolute length, because that needs n_g from outside.

I also tried to get n_g from the single-ended channels instead. For that I built an optical netlist out of the GDS — every waveguide polygon contributes its centre-line length, every component contributes the distance between its own ports, and Dijkstra from a coupler gives the distance to every interface. It found what looked like a clean answer: three predicted interfaces matching within 0.7 of a resolution cell and giving the same n_g to 0.08 %.

**It doesn't hold, and I want to be explicit about why.** The netlist has 690 interfaces across 29 channels, so at a tolerance of two resolution cells there is a candidate near almost any position you predict. Those matches were *selected* by the n_g I had assumed, so they can't then be evidence for it. The test that settles it: sweep n_g from 3.0 to 4.0 and see how well the best assignment fits. If the data contained the information there would be a clear maximum near 3.48. Instead the curve is flat across the whole range, with its maximum at n_g = 3.02.

Two side results from that chip. The two coupler pairs couple very differently — the bottom pair returns 13.5 dB more than the top one, which puts the top pair at about 4.9 dB per transit against a spec of 1.5 dB typical / 4 dB max. I think that's the fibre-array glueing rather than the SSCs. And I had no map of which fibre goes to which coupler, so I worked it out from the measurements: fibre n goes to coupler b(32−n). I confirmed it twice, once on a channel that should run into the circuit (it does, with a whole forest of peaks) and once on a channel that should be a dead-end stub (it is — one sharp reflector and nothing behind it).

### 4.3 The Ligentec SiN chip — the facet, and nothing else

The current chip is two chips in one die: a **Ligentec SiN** part with a 95-channel fibre array along its bottom edge (127 µm pitch, lensed edge couplers), and an **HHI InP** part above it, joined by a 132-port chip-to-chip interface at 92 µm pitch. Chip channel number = 96 − patchcord fibre number. I've measured two of them: **MAP2672**, and since today **MAP2680**, which has metallisation (bondpads and traces) where MAP2672 has none.

> 📈 **PLOT — insert `ligentec_facet_zoom_four_channels.png` here**

**Top panel:** where the facets of the four measured channels sit, counted from the connector plane. They spread over 2.40 mm between channel 52 and channel 95 — and that spread is the **length difference of the array fibres**, not anything about the chip.

**Bottom panel — this is the strongest single piece of evidence I have.** Same four channels, but each one re-centred on its own facet, so the x axis means "distance behind your own facet". These four channels are physically very different: channel 95 is a pure 199.5 µm loopback with no components at all, channel 52 runs into a 1×2 MMI at 8.9 mm, channel 48 has a structure at 6.5 mm. If those components reflected anything, the curves would have to differ exactly there.

**They lie on top of each other**, bump for bump, including the features at +7.5 mm and +11.5 mm. So what I see behind the facet is the instrument, not the chip.

> 📈 **PLOT — insert `ligentec2680_channel52_component_search.png` here**

The same conclusion, but done as a statistical test, on the new chip MAP2680, channel 52, with both sweep spans. The bottom two panels have the design positions of the real components marked as grey bands (wide because they span n_g,chip = 1.80–2.00), taken from the GDS: edge coupler at 0.5 mm, an X1 crossing at 3.5–3.9 mm, a pitch split and a 1×2 MMI at 10.8–12.1 mm behind facet A.

The test: take the maximum inside each predicted window, and compare it against equally wide control windows slid across 1–40 mm behind the facet. If a component is really there, its window should stand out from that null distribution.

| channel | component | window | 1520–1570 nm | 1505–1625 nm |
| --- | --- | --- | --- | --- |
| 52 | X1 crossing | 3.53–3.93 mm | +31.6 dB, **7 %** | +34.5 dB, **7 %** |
| 52 | pitch split | 10.80–12.01 mm | +28.1 dB, 34 % | +31.1 dB, 24 % |
| 52 | MMI 1×2 | 10.93–12.14 mm | +28.1 dB, 28 % | +31.1 dB, 21 % |
| 48 | pitch split / MZM | 7.90–8.78 mm | +29.0 dB, 24 % | +30.8 dB, 22 % |
| 48 | MMI 1×2 | 7.93–8.81 mm | +29.0 dB, 27 % | +29.3 dB, 24 % |
| 48 | straight heater | 8.16–9.07 mm | +29.0 dB, 28 % | +29.3 dB, 28 % |
| 48 | MMI 2×2 | 8.69–9.65 mm | +25.8 dB, 32 % | +25.2 dB, 39 % |

(The percentage is the fraction of control windows that reach or beat the predicted one. Below 5 % would be interesting.)

**Not a single detection.** The peak near 3.85 mm looks like something in the plot, but at 7 % it isn't separable from the multipath forest — with 92 control windows you expect about 5 hits purely by chance. The full sweep span buys 3–4 dB more dynamic range, but the percentages don't improve, because the forest rises along with the signal.

**Why that's actually the expected answer.** The only things on a photonic chip that reflect strongly are air facets. Taper tips are adiabatic on purpose, MMI and crossing interfaces only reflect through mode mismatch (−40…−50 dB), and a heater is optically invisible. On top of that, everything except the input facet has to get back out through the fibre-chip coupling a second time.

That also explains something that confused me: channels that give a clear signal in plain transmission (laser in one side, power meter on the other) give nothing in reflection. Three effects stack up. First, the return trip doubles every loss in dB — a path with 30 dB insertion loss is still fine in transmission but comes back with 60 dB in reflection, and I only have ~71 dB of dynamic range. Second, the SiN-to-InP edge is deliberately **angled** to suppress reflections, and it adds a second die-to-die coupling that gets crossed twice. Third, the InP part contains SOAs, and an **unbiased** SOA is strongly absorbing at 1550 nm — easily tens of dB over a 1150 µm section, one way. I think that third one dominates.

> 📈 **PLOT — insert `facet_comparison_both_ligentec_chips.png` here**

Three fibres × two chips, all six in one figure: overview on top, the facet region at absolute position in the middle, and each trace re-centred on its own facet at the bottom. The dotted lines in the overview are each scan's RMS noise floor, so you can read the dynamic range straight off.

Two results:

1. **The new chip sits ~1.7 mm closer.** Measured relative to the internal anchor (which sits *before* the chip, so most systematics cancel), fibre 1 and fibre 44 agree: −1.66 and −1.82 mm. That's just a different chip mounting. Fibre 48 disagrees — but fibre 48 is also the channel where the two MAP2672 sessions contradict *each other* by 2.4 mm, so the odd one out is the old data, not the new chip.
2. **The −3 dB peak width belongs to the fibre, not to the chip:**

| fibre | MAP2672 | MAP2680 |
| --- | --- | --- |
| f1 | 33.0 µm | 31.0 µm |
| f44 | 35.4 µm | 43.8 µm |
| f48 | **81.9 µm** | **82.8 µm** |

Fibre 48 is twice as wide as the others on **both** chips, and the two numbers agree to 1 µm across two different physical chips. That can't be a chip effect.

### 4.4 Two smaller results

**Index matching with IPA works, and by the amount you'd expect.** I compared the raw channels with and without isopropanol on the facet, using the aux as a control:

| quantity | without IPA | with IPA | Δ |
| --- | --- | --- | --- |
| Ch1 AC (fringe amplitude) | 0.006938 mW | 0.002954 mW | **−7.42 dB** |
| Ch1 DC | 0.075185 mW | 0.015552 mW | **−13.69 dB** |
| Ch2 AC (aux, control) | 0.149320 mW | 0.148551 mW | **−0.04 dB** |

The aux is identical to 0.04 dB, so the laser, the LO and the aux path were unchanged and everything that moved in Ch1/Ch3 came from the measurement path. And the two numbers agree with each other: AC ∝ √(P_LO·P_back) while DC ∝ P_back, so the AC change should be exactly half the DC change in dB. −13.69/2 = −6.85 against a measured −7.42 — that's 0.6 dB, two independent quantities telling the same story. So **IPA dropped the back-reflection by about 14 dB**, which sits between the Fresnel predictions for glass/air → glass/IPA (~15 dB) and SiN/air → SiN/IPA (~6.6 dB).

One problem: with IPA the facet peak got **wider** (16.3 → 26.9 µm). My guess is that the isopropanol evaporates during the 2–4 minute sweep, so the index match changes *while* I'm measuring. Non-volatile gel would be the fix.

**Bare fibre arrays without any chip.** Meisu and PHIX arrays measured on their own:

| array | channels | facet position from the connector plane |
| --- | --- | --- |
| Meisu | 4, 8, 9, 12 | 1075.40 … 1076.37 mm (spread 0.97 mm) |
| PHIX | 1, 8 | 1067.51, 1069.14 mm |

The ~8 mm between the two manufacturers is just array length. But the **coupling varies by 13 dB between channels of the same array**, and re-plugging a bad channel only recovers 1–2 dB of that — so it's the array, not the connection.

---
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

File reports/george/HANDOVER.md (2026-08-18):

# OFDR Reflectometer — Project Handover

**Date:** 2026-08-12 · **For:** incoming student + any Claude session taking over
**Scripts:** `ofdr_process.py` (main pipeline), `ofdr_diagnose.py` (discriminator
toolkit), `make_test_data.py` (synthetic validator, CSV format)

Read this top to bottom once. The single most important lesson of the project
so far is at the end of §5: three plausible explanations for one artifact were
wrong before the fourth was proven, and each was eliminated by a *measurement*,
not a better story. Work that way.

---

## 1. What is being built

An optical frequency-domain reflectometer (OFDR), functionally a home-built
Luna OBR: sweep a tunable laser, interfere the light returned from a fiber
under test with a local oscillator copy, FFT the interferogram, and read out
every reflection along the fiber as a peak — position, magnitude, micron-scale
resolution.

**Core physics in one equation.** With the laser at optical frequency ν, each
reflector at round-trip delay τᵢ contributes to detected power:

    I(ν) = Σᵢ 2·√(P_LO·Pᵢ)·cos(2π·τᵢ·ν + φᵢ)

The interferogram *as a function of ν* is a sum of sinusoids; each reflector
is one tone whose frequency is its delay. FFT over ν → reflectogram.

**The numbers that govern everything:**

| Quantity | Formula | Current value |
|---|---|---|
| Resolution | Δz = c/(2·n_g·Δν_span) | 7.0 µm (120 nm span) |
| Nyquist range | z_max = c/(4·n_g·δν_step) | 0.42 m (1 pm steps) |
| Sample spacing in ν | δν = c·δλ/λ² | 132→114 MHz across sweep (18% chirp!) |
| Fringe period of a path at z | λ²/(2·n_g·z) | 0.78 pm at z = 1.05 m |
| n_g (SMF-28, 1550 nm) | — | 1.468 |

Range·×·resolution is fixed by the point count: range/resolution = N/2 cells.
Sweep *speed* cancels out of everything except the required sample rate.
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

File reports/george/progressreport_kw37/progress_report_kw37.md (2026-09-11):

Hi — update for this week. This one is about the HHI chip, not fibres.

## What I set out to do

I wanted to measure a waveguide length on the chip with the reflectometer. The structure I picked is the little loop at the top left of HHI_RUN_1 — the one that connects two neighbouring edge couplers to each other. I first extracted its length from the GDS by summing up the arcs and straights along the centre line:
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

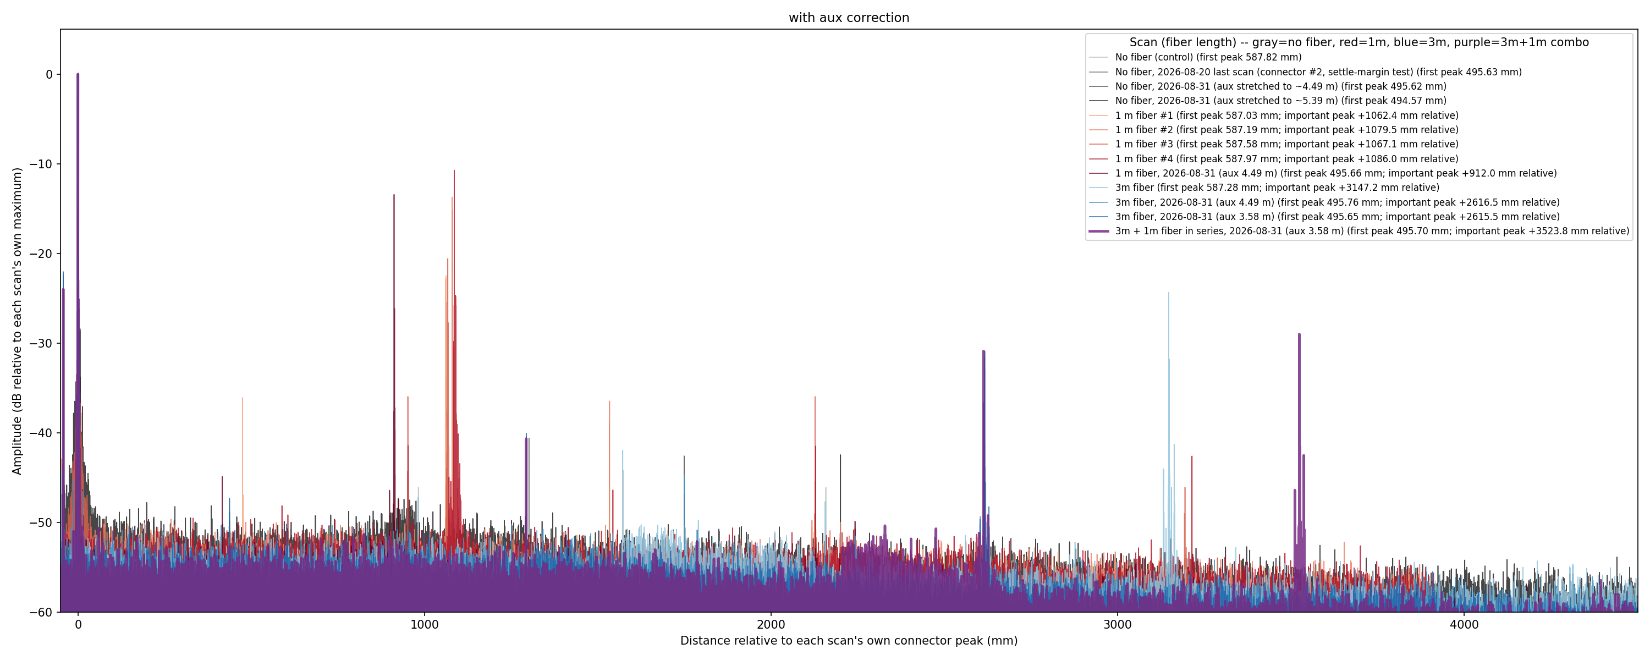
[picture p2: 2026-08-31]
reports/george/progressreport_kw36/fiber_comparison_relative_to_connector.png

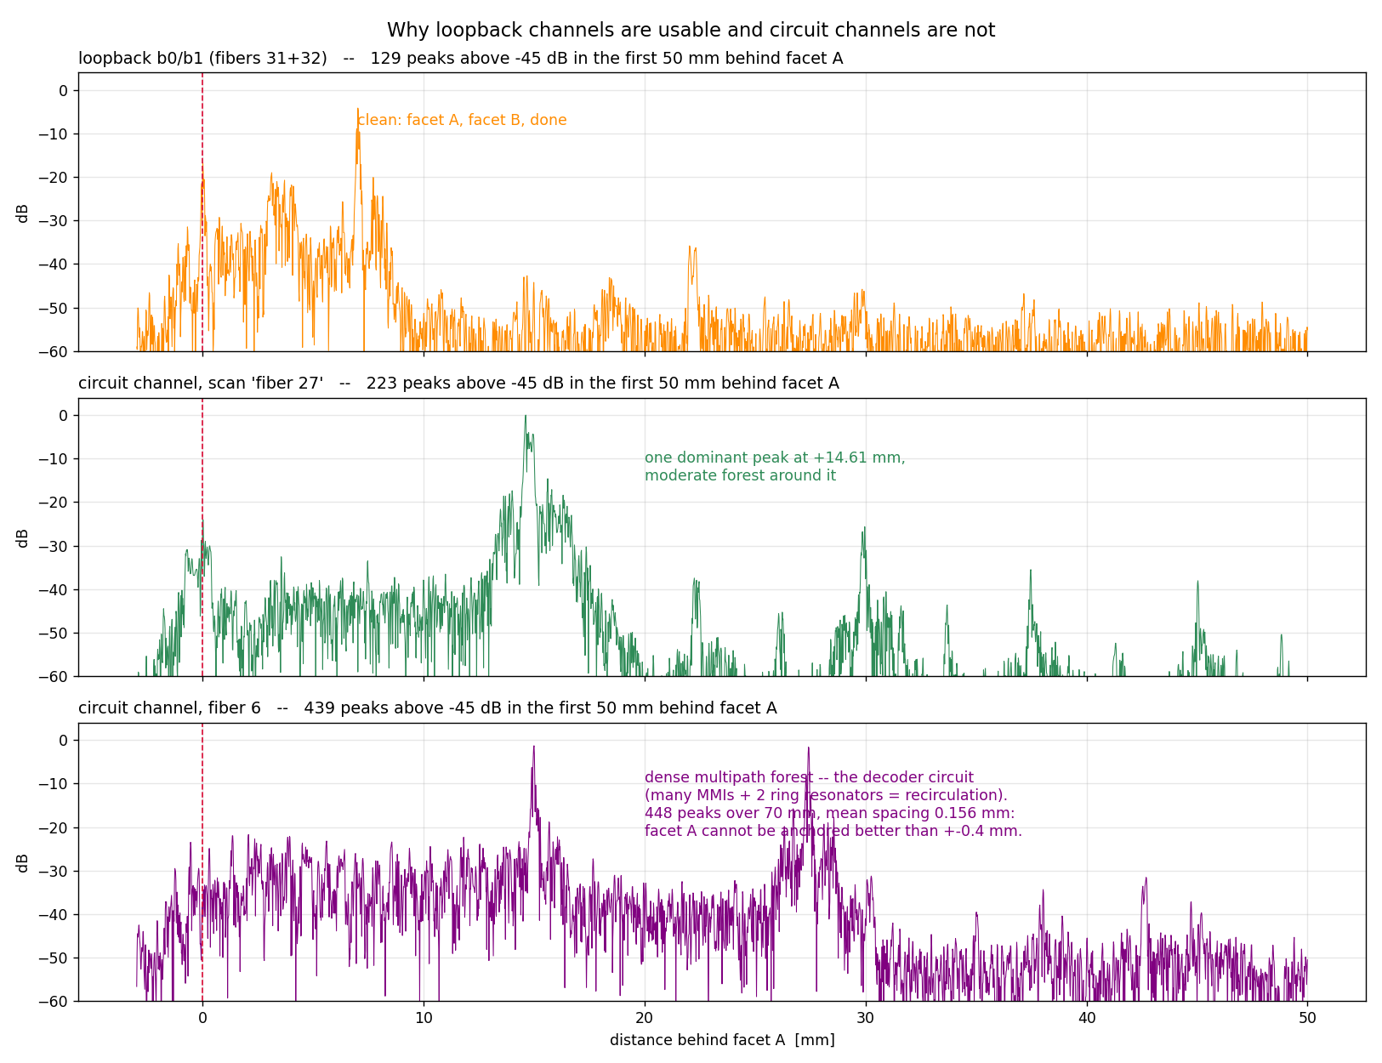
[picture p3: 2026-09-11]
reports/george/progressreport_kw37/why_circuit_channels_fail.png

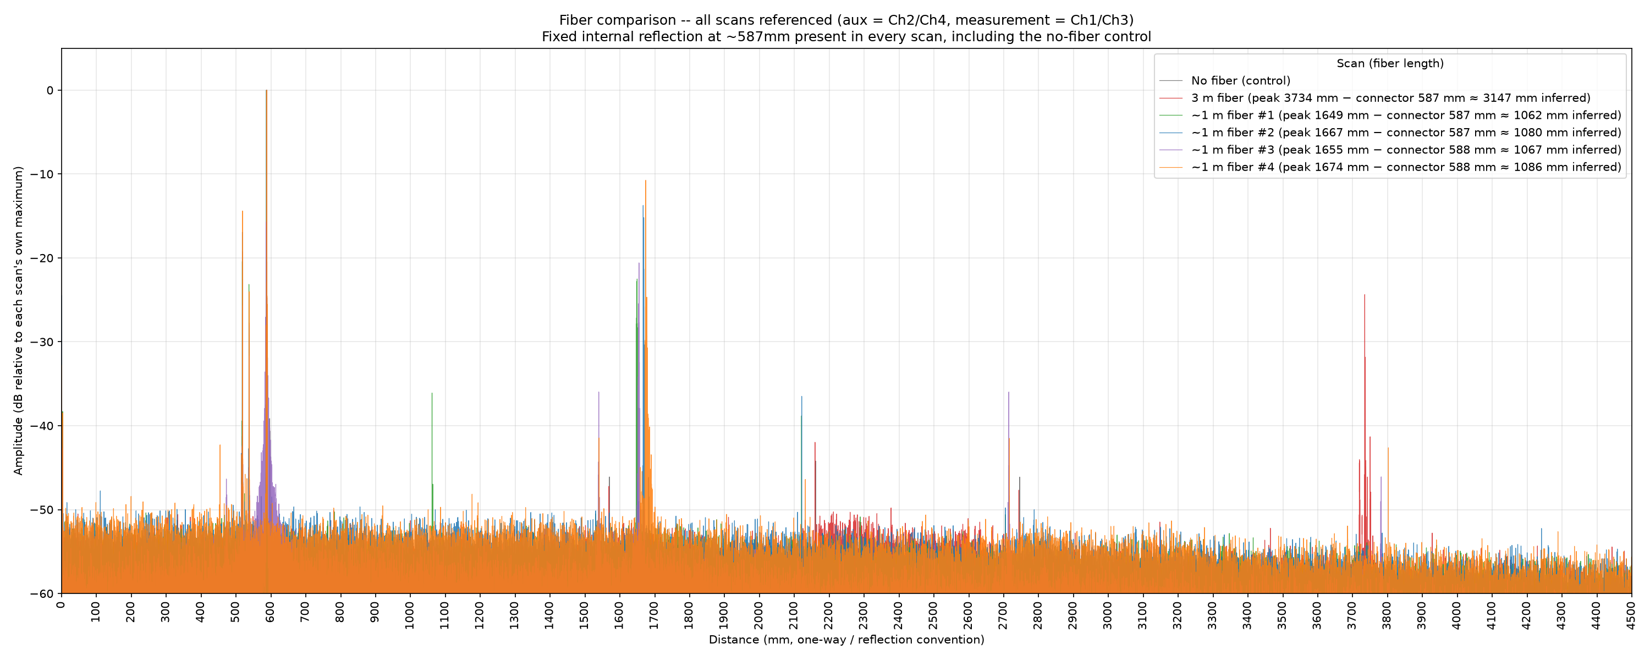
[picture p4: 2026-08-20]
reports/george/progressreport_kw34/comparison_plot.png

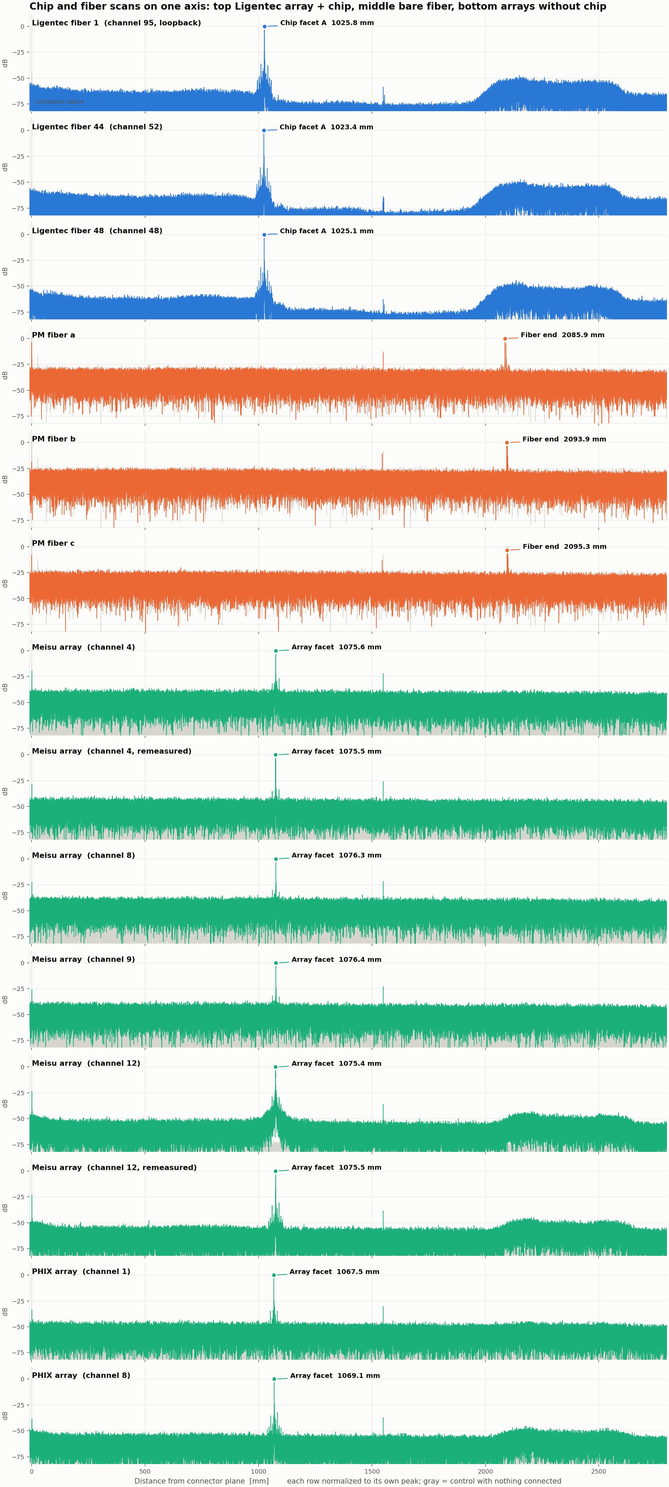
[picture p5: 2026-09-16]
reports/companywide/kw38/plots/overview_all_scans_from_connector_plane.png

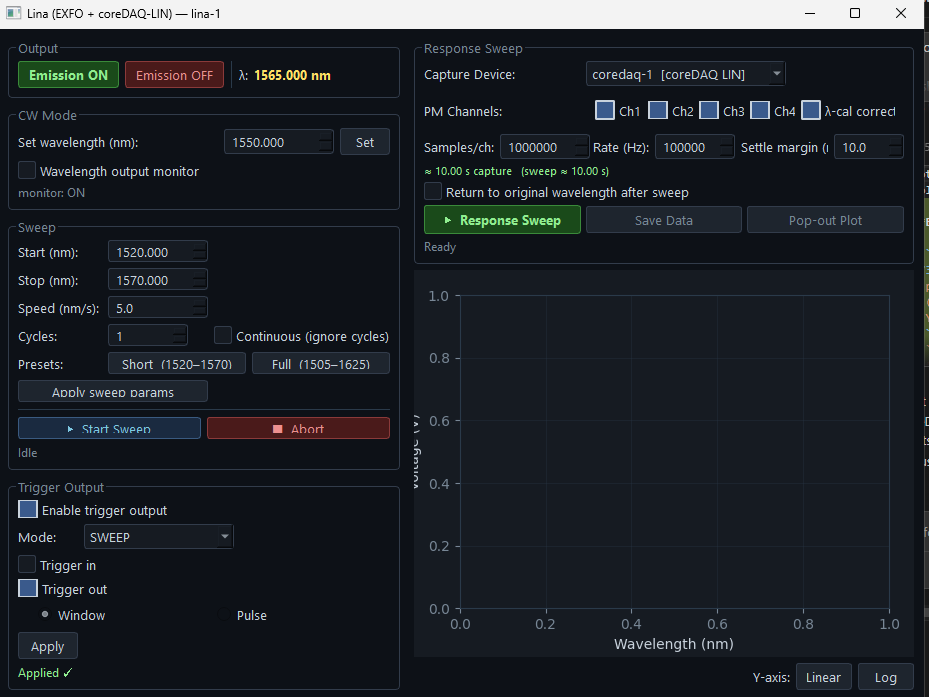
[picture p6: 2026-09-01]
reports/george/progressreport_kw36/Tuesday/linaterminal.png

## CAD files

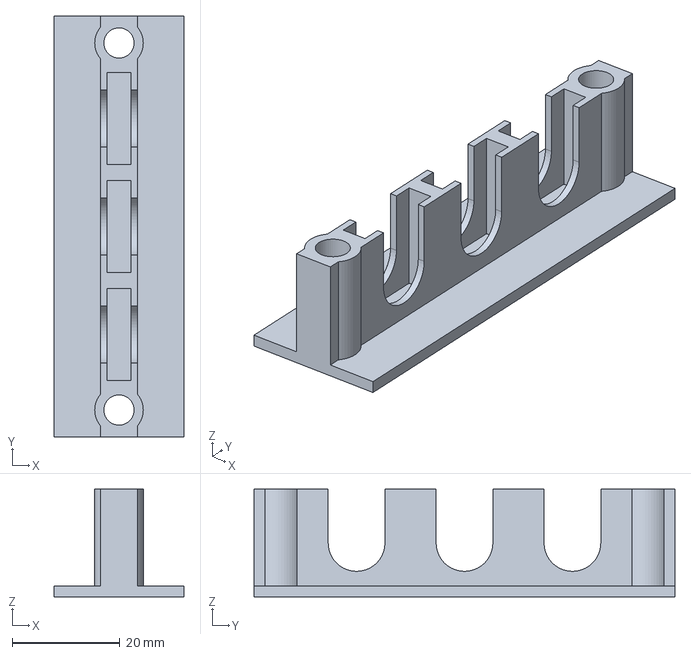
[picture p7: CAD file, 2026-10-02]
CAD/step/connector_holder_print.step
24.0 x 78.0 x 20.0 mm

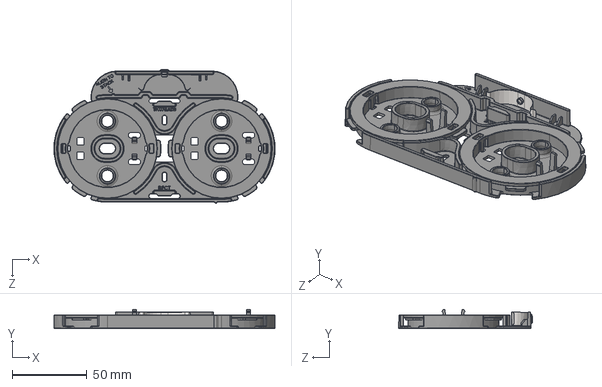
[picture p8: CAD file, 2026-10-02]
general documents/fiberholder.step
147.6 x 12.8 x 89.3 mm

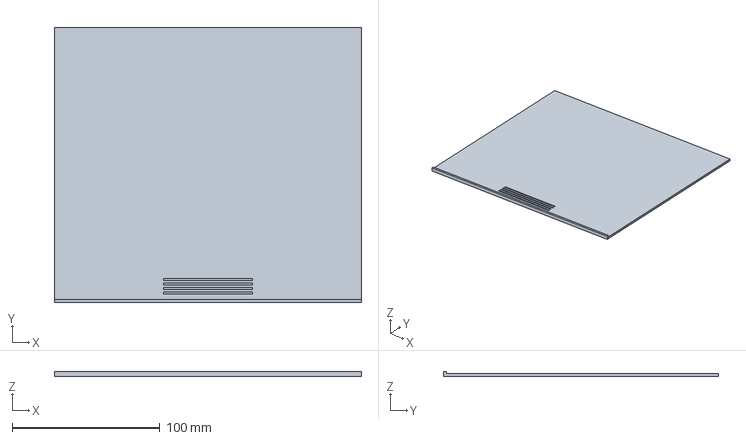
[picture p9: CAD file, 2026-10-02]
CAD/step/lid_print.step
208.1 x 186.6 x 3.40 mm

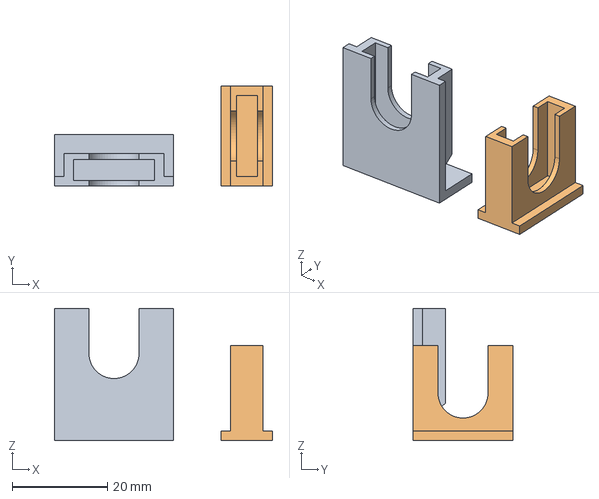
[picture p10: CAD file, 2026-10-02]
CAD/step/test_print.step
45.8 x 21.0 x 27.8 mm
test_wall_connector
test_tower_holder

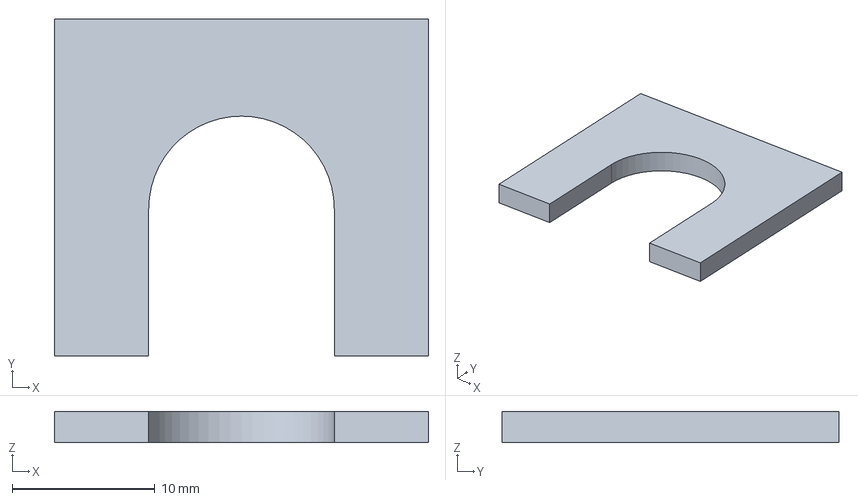
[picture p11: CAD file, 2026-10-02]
CAD/step/keeper.step
26.2 x 23.6 x 2.20 mm

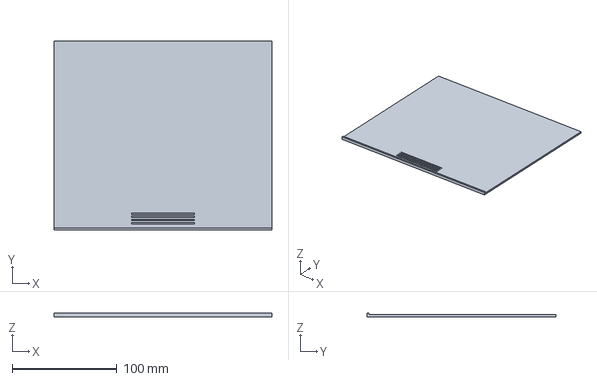
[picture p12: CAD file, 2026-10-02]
CAD/step/lid.step
208.1 x 180.6 x 3.40 mm

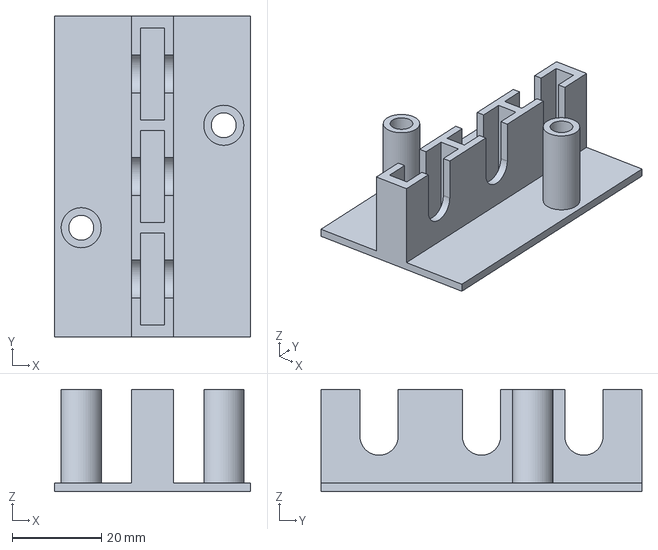
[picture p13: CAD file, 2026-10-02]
CAD/step/connector_holder.step
44.0 x 72.0 x 23.0 mm

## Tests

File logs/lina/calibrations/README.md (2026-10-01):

# Calibrations

One file per sweep configuration. The GUI and the scripts look them up here
automatically by matching start wavelength, stop wavelength and sweep speed
(±0.05 nm, ±2 %).

Reasoning: `../report.md`, §3.

## Contents

| File | Configuration | Fit |
|---|---|---|
| `lina_wl_cal_1520.0-1570.0nm_5.00nms.json` | 1520 → 1570 nm at 5 nm/s | degree 2, **3.1 pm rms**, 5.1 pm max |

Measured on 2026-09-01 with the TOF1550 filter at 8 positions (1530…1565 nm),
`exfo-1` + `coredaq-1` at 5 kHz. Raw data: `../data/01_wavelength_calibration/`.

## What is inside

- `fit.coeffs` — λ(t) polynomial, **nm versus seconds from the trigger edge**.
  Being in seconds makes it rate-independent (verified: measured at 5 kHz,
  applied to a 100 kHz capture to −3 pm).
- `derived.buffer_time_s` — when the sweep reaches the start wavelength
  (+0.0041 s, i.e. essentially at the trigger edge).
- `derived.sweep_end_s` — when the sweep ends (9.8895 s of a 12.00 s buffer);
  everything after that is the laser's return slew and gets cropped.
- `derived.effective_speed_nm_s` — 5.1174 nm/s against 5.0000 commanded.
- `points` — the 8 measured (time, wavelength) pairs the fit came from.

## Validity

**A calibration is valid only for the configuration it was measured at.** Any
other start/stop/speed needs its own ~3-minute run:

```bash
python lina/scripts/lina_sweep_test.py --channels 2 calibrate \
    --start <nm> --stop <nm> --speed <nm/s> --rate 5000 --trust-filter \
    --filter-positions <list of nm inside the range>
```

The lookup refuses a mismatched calibration rather than guessing. It matches on
start/stop/speed only, not on the coreDAQ — the λ(t) fit is a property of the
EXFO sweep and the trigger timing. The existing file was measured with the Mk1
LINEAR coreDAQ; it should carry over to the Mk2 (a µs-scale trigger-latency
change is fm at 5 nm/s), but **one confirming calibration run on the Mk2 is
still outstanding**. Drift is not
a concern: measured at +0.0 pm/min over 18 minutes, so a calibration does not
go stale within a session.

## `aux_mzi.json` — the aux delay, as a watchdog

**Not present yet.** This file holds one number, `tau_aux_s`, the aux MZI's
delay. It is deliberately NOT what sets any axis: `aux_wavelength_axis` takes
its scale from the commanded sweep endpoints, so a stale value here cannot
corrupt a measurement. Its two jobs are:

* **staleness.** Every sweep implies an aux delay in passing (fringes divided
  by the endpoints' frequency span). Compared against this file, a changed
  bench announces itself instead of being discovered months later.
* **aliasing.** A cleanly aliased fringe is invisible in the capture — folding
  a pure tone gives another pure tone with a smooth, monotonic phase, so every
  intrinsic check passes. The implied delay is the only thing that gives it
  away, and without this file that check cannot run.

**Why it is missing rather than filled in.** The value measured on 2026-09-01
(20.3877 ns, from `lina/analysis/` on the OFDR captures) no longer describes
the bench. Measured 2026-09-15 on two fibres over two sweep windows, the
captures imply **20.635 ns** (1520–1570 nm, anchored by the λ(t) calibration
above) and **20.66 ns** (1505–1625 nm, anchored by the commanded endpoints) —
about +1.2 % on the stored figure, i.e. roughly 5 cm of fibre. An independent
sign of the same change: the measurement pair now correlates +0.4 to +0.5
where `report.md` §6.1 recorded −0.88 to −0.99, so the arm was re-patched.

A 2.07 m reference fibre backs the new figure: it reads 2.069 m with the
correction and 2.037 m without.

Writing the file is therefore a measurement decision, not a code one. Either
take 20.635 ns from the λ(t)-anchored captures, or — better — re-run the
three-minute filter calibration, which produces a fresh λ(t) *and* a fresh
aux delay for the bench as it stands:

```bash
python lina/scripts/lina_sweep_test.py --channels 2 calibrate \
    --start 1520 --stop 1570 --speed 5 --rate 5000 --trust-filter \
    --filter-positions 1530,1535,1540,1545,1550,1555,1560,1565
```

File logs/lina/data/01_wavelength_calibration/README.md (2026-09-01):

# Data: λ(t) wavelength calibration (2026-09-01, 15:27–16:21)

Everything in this folder was recorded with the **TOF1550 filter in the optical
path**. The filter was purely an instrument: it transmits only near its centre
wavelength and therefore marks a known wavelength at a measurable time in the
capture. For the actual OFDR measurements (`../02_ofdr_measurements`) it was
removed again.

Devices: `exfo-1` (T200S) + `coredaq-1` (LINEAR, FW v4.2) + `tof1550-1` (COM6).
Produced with `lina/scripts/lina_sweep_test.py`.

Full reasoning and all results: `../../report.md`, §2–§5.

---

## The consideration

The GUI mapped the capture onto wavelengths with
`linspace(start, stop, n_samples)`. That assumes the buffer contains exactly
the sweep, and that the sweep runs at the commanded speed. Both are false.
Rather than infer the mapping, it was measured.

---

## Files

| File | Produced by | What it shows |
|---|---|---|
| `filter_cw_t1_*.csv/.png` | `filter-cw --filter-nm 1550 --span 1.5 --step 0.025 --channels 1,2,3,4` | The passband measured in CW: peak 1549.98–1550.00 nm, FWHM 0.15–0.23 nm (datasheet 0.21 nm), contrast 447–1173×. Ground truth **independent** of the filter's own scale. Also shows the autorange notch on the peak. |
| `sweep_t2_*.npz/.csv/.png` | `sweep --rate 10000 --filter-nm 1550` | First raw capture: **one** broad peak at 5.9065 s (sweep crossing, 59 ms) and **one** narrow peak at 10.1195 s (2.8 ms) = the laser's **return slew**. First direct evidence that the tail is inside the buffer. |
| `sweep_cal_15*_2026-09-01_15-39*` … `15-41*.npz` | `calibrate --filter-positions 1530,…,1565 --rate 5000` | The 8 calibration points. Peak times 1.9622 s (1530 nm) … 8.8909 s (1565 nm). |
| `sweep_cal_1530_…15-36-02.npz` | first, aborted calibration run | That run failed at its second point (USB read stall, report §4.2). Only the 1530 nm point exists. **Not** used in the calibration. |
| `lina_wl_cal.json` | result of the calibration run | The fit. Identical to `../../calibrations/lina_wl_cal_1520.0-1570.0nm_5.00nms.json`, which is the copy the GUI and the scripts look up automatically. |
| `calibration_cal1_*.png` | `plot-cal` | Fit, residuals per degree, error of the uncorrected axis, residual-versus-degree, stability. This is the figure that justifies degree 2. |
| `SUMMARY_lina_wl_cal.png` | `lina_cal_summary.py` | Six-panel overview of all calibration results. Regenerable. |
| `sweep_t100k_*.npz/.png` | `sweep --rate 100000 --cal …` | **The rate-independence test:** calibration measured at 5 kHz, applied here to 100 kHz / 1.2 M samples → marker at 1549.9970 nm, **−3 pm**. The same file also shows the naive axis at −5388 pm. |
| `sweep_nopark_*.npz/.png` | `sweep --park-settle 0` | **Refutes the settling hypothesis:** without parking/settling the marker sits at 5.9067 s versus 5.9064 s with a 5 s park → < 1 pm difference. |
| `repeat_rep1_*.csv` | `repeat --runs 5` | Repeatability over 1.7 min: 0.8 pm rms, 2.0 pm p-p. |
| `repeat_drift_*.csv` | `repeat --runs 6 --interval-s 180` | Drift over 18 min: 0.7 pm rms, **+0.0 pm/min**. No measurable drift → one calibration is enough. |

The `.csv` files are text copies of the `.npz` captures (one row per sample).
They are no longer written automatically (`--csv` enables them), because a
1.2 M capture is ~25 MB as CSV versus ~30 kB as compressed NPZ.

---

## Key results

| Quantity | Value |
|---|---|
| fit | degree 2, **3.1 pm rms** (degree 1: 27.2 pm with a systematic arch) |
| effective sweep rate | 5.1174 nm/s versus 5.0000 commanded |
| trigger dead time | +0.0041 s (essentially zero) |
| sweep in the buffer | t = 0.004 … 9.889 s of 12.00 s (82.4 %) |
| error of the old linear axis | **−5.4 nm** at 1550 nm, **−10.5 nm** with `Buffer time = 2 s` |
| with the calibration | **−3 pm** |
| repeatability / drift | 0.7 pm rms / +0.0 pm/min over 18 min |

---

## Reproducing

```bash
# Passband (the filter must be in the path)
python lina/scripts/lina_sweep_test.py --channels 1,2,3,4 \
    filter-cw --filter-nm 1550 --span 1.5 --step 0.025

# Calibration (~3 min); publishes the result to lina/calibrations/
python lina/scripts/lina_sweep_test.py --channels 2 calibrate \
    --start 1520 --stop 1570 --speed 5 --rate 5000 --trust-filter \
    --filter-positions 1530,1535,1540,1545,1550,1555,1560,1565

# Regenerate the overview figure (no hardware)
python lina/scripts/lina_cal_summary.py --data lina/data/01_wavelength_calibration
```

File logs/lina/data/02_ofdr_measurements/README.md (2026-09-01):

# Data: OFDR fibre-length measurements (2026-09-01, 17:03–17:57)

Recorded with the **TOF1550 filter removed** — these are the real
measurements. Each capture is one sweep, all four channels, 100 kHz,
1,050,000 samples per channel.

Setup: `exfo-1` + `coredaq-1`, 1520 → 1570 nm at 5 nm/s.

- **Ch1, Ch3** — measurement MZI, contains the test fibre
- **Ch2, Ch4** — reference ("aux") MZI, own path imbalance 4.16 m

Produced with `lina/scripts/lina_ofdr_test.py`. Full reasoning: `../../report.md`,
§6–§9.

---

## The consideration

An FFT of the interferogram gives a delay, and therefore a length — but only if
the signal is uniform in **optical frequency**. The coreDAQ samples uniformly
in **time**, and the EXFO sweeps 1–2 % fast and slightly non-uniformly. The aux
MZI's fixed delay makes its fringe phase the optical-frequency axis, so the
measurement is resampled onto a uniform aux-phase grid before the FFT.

Both channel pairs are evaluated, each using the *other* pair as its phase
reference. That makes them two independent measurements of the same fibre,
which is the strongest cross-check available without an external standard.

---

## Naming

`<state>_...` — which fibre was connected when the capture was taken:

| Prefix | State |
|---|---|
| `1mA_` | test fibre "1mA" (nominally 1 m) |
| `1mB_` | test fibre "1mB" (nominally 1 m) |
| `3mB_` | test fibre "3mB" (nominally 3 m) |
| `3mB1mB_` | 3mB and 1mB connected in series |
| `nofiber_` | no test fibre connected |

`sweep_ofdr_*.npz` = raw capture (4 channels, cropped to the sweep window by
the λ(t) calibration). `ofdr_*.png` = the diagnostic figure produced with the
capture. `*_PEAKS_*.png` / `OVERLAY_*.png` = evaluation figures, regenerable
from the NPZ at any time.

---

## Files

| File | What it shows |
|---|---|
| `OVERLAY_all.png` | **The main result.** All five states in one figure, one colour each. Upper panel: axis reads test-fibre length. Lower panel: the aux pair in its own axis. |
| `1mB_sweep_ofdr_run1/2/3_*.npz` | Three repeats of the same state → peak reproducibility ±0.03 mm (1.14795 / 1.14800 / 1.14797 m in the raw axis). |
| `1mA_sweep_ofdr_*.npz` | The fibre swap. Two peaks move by ±31 mm, the strong peaks do not — this is what showed that the strongest peak is *not* the fibre. |
| `nofiber_sweep_ofdr_*.npz` | **The decisive measurement.** Exactly the two peaks that depend on the fibre disappear; everything else stays. Without this, the peak assignment would be guesswork. |
| `3mB_sweep_ofdr_*.npz` | Confirms the factor of two: 3 m fibre → 6.051 m of path, so the fibre is traversed twice. |
| `3mB1mB_sweep_ofdr_*.npz` | Additivity test: predicted 4.06533 m from the two single measurements, measured **4.06334 m** → 2.0 mm. Also shows the connector between the fibres at 3.03 m. |
| `sweep_ofdr_3mBonly_check_*.npz` | Control capture taken after the GUI button produced a wrong length — the script found 3.02522 m on the same hardware minutes later, which localised the problem to the GUI capture path (report §11.1). |
| `CROPSCAN_3mB1mB.png` | The crop scan that **refuted** the idea that the first 10 nm must be discarded: SNR unchanged at 41–42 dB, FWHM worse at heavy crops. |
| `*_PEAKS_stacked.png` | Aux above, measurement below, in the raw axis (earlier presentation stage). |
| `*_PEAKS_fibrelength.png` | Same, but the measurement axis reads fibre length (offset subtracted). |
| `1mB_PEAKS_testfiber_0-3m.png`, `1mB_PEAKS_aux_1-5m.png` | Intermediate stage: separate zoomed views before the stacked figure existed. |
| `1mB_sweep_..._fft_*.png` | Re-evaluations of the same capture with different processing (with/without high-pass, swapped channel roles) — the steps that identified which pair is which. |

---

## Results

Axis reads test-fibre length (reflection convention, MZI offset 0.57396 m
subtracted):

| Fibre | Peak | Prediction | dB |
|---|---|---|---|
| 1mB | **1.0397 m** | — | −22.4 |
| 1mA | **1.0553 m** | — | −18.4 |
| 3mB | **3.0256 m** | — | −31.2 |
| 3mB + 1mB | **4.06334 m** | 4.06533 m (sum of the two) | −31.9 |
| no fibre | no peak | — | — |

- 1mA is **15.6 mm longer** than 1mB.
- Lengths are additive to **2.0 mm (0.05 %)**.
- Repeatability ±0.03 mm; systematic uncertainty ~±2 mm from the peak's
  sub-lobe structure (report §9.1).
- All lengths scale linearly with `--n-group` (1.4682, SMF-28 at 1550 nm).

---

## Reproducing

```bash
# New measurement (filter must be OUT of the path)
python lina/scripts/lina_ofdr_test.py --tag myrun measure \
    --start 1520 --stop 1570 --speed 5 --rate 100000

# Both spectra of one capture, stacked, axis reading fibre length
python lina/scripts/lina_ofdr_test.py --pad-factor 4 --n-peaks 3 peaks \
    --raw lina/data/02_ofdr_measurements/3mB_sweep_ofdr_run1_*.npz \
    --meas-offset-m 0.57396

# The overlay of all states
python lina/scripts/lina_ofdr_test.py --pad-factor 4 overlay \
    --raw 1mA=<npz> 1mB=<npz> 3mB=<npz> 3mB+1mB=<npz> nofiber=<npz> \
    --meas-offset-m 0.57396 --meas-xlim 0,4.5 --aux-xlim 1.5,4.5
```

The `--meas-offset-m 0.57396` value is the measurement MZI's own path
imbalance, taken from the `nofiber_` capture. Re-measure it whenever the
interferometer itself is changed.

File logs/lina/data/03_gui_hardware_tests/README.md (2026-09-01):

# Data: headless GUI hardware tests (2026-09-01, 16:43–17:58)

Output of `lina/scripts/lina_window_test.py`. Each file is the result of the
**real** Lina window from AkheLab being driven on real hardware without
clicking: the actual `LinaWindow` with the actual `DeviceRegistry` is built on
Qt's offscreen platform, the capture device is selected in its combo box, the
channels are ticked, and "Response Sweep" is pressed.

Purpose: verify a GUI change against hardware, and see exactly what the window
would show. The capture therefore runs through the GUI's own
`_CoreDAQSweepWorker` — the same acquire path, arming arithmetic and λ(t) axis
code a user gets.

Full reasoning: `../../report.md`, §4 and §10–§11.

---

## The consideration

The scripts were written first because the GUI could not be debugged
interactively from here. Once the GUI carried the same features, it needed to
be tested on hardware too — but a Qt window cannot be clicked from a terminal
session. Driving the real window offscreen tests the GUI's own code rather than
a parallel re-implementation, which is the only way a GUI test proves anything.

---

## Files

| File | What it shows |
|---|---|
| `gui_response_sweep_*.png/.npz` | The sweep the window produced: power versus the calibrated wavelength axis, plus the per-channel arrays. |
| `gui_ofdr_*.png` | The figure the new **"OFDR Plot"** button draws (aux above, measurement below). |

---

## What these runs established

1. **The λ(t) axis works in the GUI.** 988,536 points spanning exactly
   1520.0000 → 1570.0000 nm, monotonic, with the status line reporting
   `✓ λ(t) deg 2, 3 pm rms`.

2. **The premature-read bug and its fix.** With 1.2 M frames at 100 kHz
   (12.00 s window against a 10.81 s sweep) the read stalled at
   4,799,488 / 4,800,000 bytes and destroyed the arming. After adding the wait
   for the armed window, the same setting read cleanly.

3. **The retry works.** Three runs at 1.2 M × 2 channels: one failed twice and
   succeeded on the third attempt, one failed once, one succeeded immediately —
   all three ended with usable data. At four channels (8.4 MB) one run
   exhausted the original 2-retry budget, which is why it is now 4.

4. **A real bug in my own module wiring, found by this test.** The reference
   channel pair was passed the string `"aux"` in `combine_pair`'s *mode*
   parameter (which only accepts `auto`/`always`/`never`), so it was silently
   **not** balanced-subtracted — only Ch2 was used. The aux phase was
   consequently unusable (3 % single-tone, 18 % non-monotonic). Fixed.

5. **An unresolved problem (report §11.1).** Even after that fix, captures
   taken through the GUI yield an aux phase with ~5 % too few fringes
   (121,636 versus 128,011 in a script capture minutes later on the same
   hardware), which stretches the distance axis by the same factor: the
   3 m fibre reads 2.846 m instead of 3.026 m. The evaluation itself was
   verified identical to the script's by running the same `evaluate()` on
   script data. Cause not yet found — **use the script for real measurements.**

---

## Reproducing

```bash
# Defaults as shipped, all four channels, plus the OFDR button
python lina/scripts/lina_window_test.py --channels 1,2,3,4 --ofdr

# Force a specific arming to reproduce the read behaviour
python lina/scripts/lina_window_test.py --channels 1,2 --samples 1200000
```

Requires the hardware to be free — close AkheLab first (LabDevice allows one
instance per serial id, and the coreDAQ's USB port is exclusive).

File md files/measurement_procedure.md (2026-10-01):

# Procedure Plan — which program, when, with which setup

**For:** Carolina · 18.08.2026

---

## ⚠ First: a correction to my own plan

In the list you quoted, steps 2.3–2.5 were listed as *"check and calibrate
the aux in the old trigger mode"*. **That doesn't work.** I ran the numbers:

```
Old trigger mode, 1 pm step        ->  range 0.42 m
An aux with 4 m arm difference     ->  appears at 2.00 m
```

The aux would fall far outside the range and would **alias against itself**.
In trigger mode, at most an aux with **ΔL < 0.83 m** could be checked — but
for a 2 m measurement path you need 4 m.

**The solution is simpler than the original plan:** τ_aux can be calibrated
in free-run mode by **counting fringes**. For this you don't need a
wavelength table at all — just the start and end wavelength you set on the
laser:

```
τ_aux = number of fringes counted / frequency span of the sweep
```

Accuracy: ~7 ppm. Completely sufficient. There's now a dedicated program for
this, `check_aux_interferometer.py`.

The order below has been corrected accordingly.

---

## The six programs at a glance

| Program | Instrument | Trigger | Channels | What it's for |
|---|---|---|---|---|
| `process_reflectogram.py` | red | old mode | Ch1, Ch2 | the existing analysis |
| `diagnose_artifacts.py` | red | old mode | Ch1, Ch2 | the four diagnostic tests |
| `calc_sweep_parameters.py` | — | — | — | desk-based planning |
| `simulate_aux_data.py` | — | — | — | simulation for practice and testing |
| **`check_aux_interferometer.py`** | **black** | **free-run** | **Ch1, Ch2** | **ruler acceptance test** |
| **`process_reflectogram_aux.py`** | **black** | **free-run** | **Ch1–Ch4** | **the new analysis** |

---

# Step by step

## S0 · Baseline · *old setup, nothing changed*

**Setup:** as it is now. **Instrument:** red CoreDAQ, trigger mode (1 pm),
2 channels, fixed measurement ranges.

```bash
python process_reflectogram.py  scan_S0.json
python diagnose_artifacts.py tuning scan_S0.json
```

**Record:**

| | expected |
|---|---|
| Main peak position | ~46.4 mm |
| Main peak width | ≤ ~21 µm |
| Slow drift | ~59 pm p-p |
| Fast jitter | ~90–110 MHz rms |

**Why:** This is your before picture. Without these four numbers you'll have
nothing to compare against later. Keep the file.

---

## S1 · Kill the fiber end · *only the test fiber touched*

**Setup:** index-matching gel on the end face, or tightly coil the last few
centimeters, or a patch cord < 35 cm. **Instrument:** unchanged.

```bash
python process_reflectogram.py  scan_S1.json
python diagnose_artifacts.py compare scan_S0.json scan_S1.json
```

**Expectation:** The median in the 6–32 cm range drops significantly. The
dirt band disappears into the noise.

**Proceed if:** The band has gotten smaller. This confirms the aliasing
diagnosis yourself — and from here on you have clean data.

*(If it does NOT get smaller: stop. Then the explanation in the handover
isn't the whole truth after all, and you need to know that before
rebuilding.)*

---

## S2 · Fix parameters · *desk work, no instrument*

```bash
python calc_sweep_parameters.py --table
python calc_sweep_parameters.py --points 1000000 --span 60 --dl 4
```

Enter what Giulio told you about the buffer question. If 1 million **per
channel**:

| | |
|---|---|
| Points | 1,000,000 |
| Sweep speed | 60 nm/s |
| Sweep from / to | 1505 → 1565 nm |
| Aux arm difference | 4 m |
| → Range | 6.95 m |
| → Resolution | 13.9 µm |
| → Aux appears at | 2.00 m |
| → Points per aux fringe | 7.0 |

If 1 million **divided by 4**, recalculate with `--points 250000` — then
you'll need to drop to 15 nm span and end up at 55.6 µm resolution.

**Print this out and hang it at the setup.**

---

## S3 · Practice on the simulation · *desk work, no instrument*

Do this **before** touching hardware, so you know the outputs.

```bash
python simulate_aux_data.py --points 400000 --speed 60 --dl 4 \
       --lam0 1505 --out sim.npz

python check_aux_interferometer.py sim.npz --lam-start 1505 --lam-stop 1529

python process_reflectogram_aux.py sim.npz --tau-aux-ns 19.587 --zmax 2.5
```

*(The 1529 is start + 400,000 × 1 µs × 60 nm/s = 1505 + 24 nm.)*

**Expectation:** `check_aux_interferometer` reports good contrast, good
monotonicity, τ_aux ≈ 19.59 ns, ΔL ≈ 4.00 m. `process_reflectogram_aux`
finds four reflectors and ends by printing `-> PASSED`.

To see what a **broken** case looks like:

```bash
python simulate_aux_data.py --points 400000 --ripple-mhz 100 --out sim_bad.npz
python check_aux_interferometer.py sim_bad.npz --lam-start 1505 --lam-stop 1529
```

There, the monotonicity check will raise an alarm. That's what it looks like
when the laser jitters too much.

---

## S4 · Install the 90/10 splitter · *a single change*

**Setup:** 90/10 right after the laser. 90% into the existing setup, 10%
left open for now (or terminated). **Instrument:** still red CoreDAQ, still
trigger mode.

```bash
python process_reflectogram.py scan_S4.json
```

**Proceed if:**

- Main peak is at the same position as in S0 (± a few µm)
- Peak width unchanged
- Everything ~0.5 dB darker — that's the inserted loss, normal

**Why:** You're checking that the splitter hasn't broken anything, **using
tools you already know**. One new thing at a time.

---

## S5 · Build and accept the aux · *now the switchover happens*

**Setup:** 10% branch → 50/50 splitter → two arms, one 4 m longer → 50/50
coupler → both outputs to **Ch1 and Ch2**.
Put the 4 m coil in a box, not loose on the table.

**Instrument:** black CoreDAQ. Single trigger on the EXFO, free-run with
1 µs. 4 channels, **fixed measurement ranges** (autoranging mid-sweep
destroys the scan). Sweep 1505 → 1565 nm at 60 nm/s.

```bash
python check_aux_interferometer.py scan_S5.json --lam-start 1505 --lam-stop 1565
```

**The program answers four questions. Proceed only if all four pass:**

| Check | Criterion | If not |
|---|---|---|
| **1 Contrast** | Visibility > 0.4 everywhere | Polarization fading → add a polarization controller in one arm |
| **2 Monotonicity** | 0% backward-running steps | **STOP.** The laser is jittering too much. Find the cause before continuing |
| **3 Calibration** | τ_aux ≈ 19.6 ns, ΔL ≈ 4 m, ≥ 4 points/fringe | ΔL doesn't match the installed fiber → remeasure |
| **4 Laser quality** | Jitter clearly below the stated limit | see check 2 |

At the end the program prints the line you need:

```
--> USE THIS NUMBER GOING FORWARD:  process_reflectogram_aux.py ... --tau-aux-ns 19.5871
```

**Write it in the lab notebook.** It's your reference standard.

**Buffer check for this scan:**

```
Sweep duration  = 60 nm / 60 nm/s     = 1.00 s
Buffer duration = 1,000,000 × 1 µs    = 1.00 s     -> exact match, no margin
```

Better to build in some margin: sweep 55 nm instead of 60, or 65 nm/s
instead of 60. If the flicker cuts off near the end of the file, the sweep
was too long.

> **Why check 4 matters more than it looks:** The handover cites 90–110 MHz
> jitter, measured *through the measurement signal* and therefore distorted
> by stray light. At ~88 MHz with a 4.5 pm period, the laser occasionally
> runs backward, and at that point **no** method can help anymore. The aux
> measures this number cleanly for the first time. This is the assumption
> the whole rebuild rests on — which is why it gets checked before anyone
> trusts a reflectogram.

---

## S6 · First real measurement · *same scan, now the measurement channels*

You don't need a new scan — `scan_S5.json` already contains all four
channels.

```bash
python process_reflectogram_aux.py scan_S5.json --tau-aux-ns 19.5871 --zmax 3.0
```

**Three checks, in this order:**

**Check 1 — is the aux where it should be?**
In the reflectogram there must be a peak at **z = ΔL/2 = 2.00 m**. That's
the aux itself, coupling in through the 20 dB coupler. If it sits elsewhere,
τ_aux is wrong.

**Check 2 — the best test you have:**
The old, known peak at **46.4 mm** must be at **exactly the same position**
as in S0 and S4. You know the answer in advance, measured with a completely
different method. If both agree, the new chain works end-to-end.

Tolerance: one resolution cell, i.e. ~14 µm.

**Check 3 — the moment of truth:**
The fiber end at ~1 m must now appear as a **sharp peak at its true
position** — no longer as a dirt band at 21 cm.

**And the ongoing check:** peak width ≲ 1.5 × the window limit (the program
prints both numbers side by side).

---

## Afterward

Once S6 checks out, you can push the configuration further:

```bash
python calc_sweep_parameters.py --points 1000000 --speed 120 --dl 4
```

120 nm/s over a 120 nm span → range 3.48 m at **7.0 µm** resolution —
today's full sharpness with 8× the range. The catch: the aux then has only
3.5 points per fringe. That's above Nyquist, but with no margin —
`check_aux_interferometer.py` will tell you. So do this afterward, not
before.

---

## Measuring with the Mk2 LOG coreDAQ (since 2026-09-17)

Everything above was written for, and measured with, the Mk1 LINEAR unit.
To keep a new scan comparable with those:

| Before / during the capture | Why |
|---|---|
| `coredaq_name` of `lina-1` in AKHExperiment `Interface/config/OBR_config.json` names the unit that is actually cabled | both units are LOG, only the serial (SN0001 / SN0002) tells them apart; the file header records it |
| Capture mode **Continuous (OFDR)**, rate **100 kHz** | every Mk1 scan is 100 kHz. The analysis resamples faster captures down, but that also filters noise the Mk1 scans folded in, so 100 kHz at the bench is the clean comparison |
| Same sweep as the scan you compare with (e.g. 1520–1570 nm or 1505–1625 nm, 5 nm/s) | resolution, range and noise floor all depend on span and point count |
| **No clamp:** the plot's y-label / script terminal must not report `LOG clamp … at ceiling` | the LOG input pins everything above ~3 mW without a flag; a clamped fringe makes ghost peaks. Turn the VOA down and repeat |
| GUI "λ-cal correction" on or off — either is fine | the GUI now stores the factor, and the analysis divides it back out |

After the capture, every tool prints one line like
`detector: Mk2 LOG SN0001 | 100 kHz | R(lambda) undone | clamp ceil 0 % floor 0 %`
and the comparison tools a table over all scans. A `WARNING` there is a
reason to stop, not to annotate.

**Not yet validated on hardware** (open, see `logs/2026-10-01.md`): that
noise floor and dB levels of a Mk2 scan match a Mk1 scan of the same setup.
Until then compare peak positions freely, dB levels only with a note.

---

## If something doesn't fit

| Symptom | First suspect | Test |
|---|---|---|
| Contrast collapses in places | Polarization in the aux arms | `check_aux_interferometer.py`, top-right panel |
| Monotonicity alarm | Laser jittering too much | `check_aux_interferometer.py`, check 2 — do **not** continue |
| τ_aux doesn't match the installed fiber | Start/end wavelength entered incorrectly, or sweep not fully within the buffer | Redo the buffer calculation |
| 46.4 mm peak at the wrong position | τ_aux wrong, or channels swapped | Check the Ch1–Ch4 assignment |
| Peaks twice as far away as expected | Reflection/transmission confused | see the "÷2" explanation |
| Flicker cuts off at end of file | Sweep longer than the buffer | Smaller span or sweep faster |
| Everything looks wrong, no idea | measure first, then explain | `diagnose_artifacts.py` has four ready-made tests |

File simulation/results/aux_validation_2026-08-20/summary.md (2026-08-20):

# Aux-pipeline validation -- 2026-08-20

12/29 gated checks passed (16 rows tracked/informational, not gated).

| scenario | category | status | pass | err_cells | notes |
|---|---|---|---|---|---|
| baseline_measured_conditions | position | ok | False | -17.893106792034892 |  |
| baseline_measured_conditions | position | ok | False | 16.436124204544758 |  |
| baseline_measured_conditions | position | ok | False | -18.473487733078493 |  |
| baseline_measured_conditions | position | ok | False | -0.09239339827795787 |  |
| baseline_tool_default | position | ok | True | 0.35139089734882617 |  |
| baseline_tool_default | position | ok | True | -0.23005679190908643 |  |
| baseline_tool_default | position | ok | True | 0.19480020790629426 |  |
| baseline_tool_default | position | ok | True | -0.20037997329210444 |  |
| doublet_2cell | resolution | resolved | True |  | valley 8.7/5.4 dB below the two peaks |
| doublet_1cell | resolution | resolved | False |  | valley 25.3/15.8 dB below the two peaks |
| weak_near_floor | amplitude | ok | None | 0.35139089734882617 |  |
| weak_near_floor | amplitude | ok | None | -0.10018998664605222 |  |
| weak_near_floor | amplitude | ok | None | -0.15028497996516402 |  |
| weak_near_floor | amplitude | ok | None | -0.20037997329210444 |  |
| weak_near_floor_elevated_noise | amplitude | ok | None | 0.35139213716554835 |  |
| weak_near_floor_elevated_noise | amplitude | ok | None | -0.10016303411516207 |  |
| weak_near_floor_elevated_noise | amplitude | ok | None | -0.1502445511727431 |  |
| weak_near_floor_elevated_noise | amplitude | ok | None | -0.20032606823032414 |  |
| nyquist_edge_inside | range | ok | True | -0.48149747068475357 |  |
| nyquist_beyond_aliased | range | aliased_as_expected | True | 0.8047021187005436 |  |
| nyquist_beyond_aliased | range | aliased_as_expected | True | -1.5947075654345586 |  |
| ripple_stress_near_limit | robustness | ok | None | -0.7339411492554491 | 23.13% backward steps (expected at this ripple) |
| ripple_stress_near_limit | robustness | ok | None | 3.2568973407076753 | 23.13% backward steps (expected at this ripple) |
| ripple_stress_near_limit | robustness | ok | None | -17.10083022590454 | 23.13% backward steps (expected at this ripple) |
| ripple_stress_near_limit | robustness | ok | None | 0.04600438020792897 | 23.13% backward steps (expected at this ripple) |
| bow_stress_2x | robustness | ok | None | 0.2367225380126685 | 0.00% backward steps (expected at this ripple) |
| bow_stress_2x | robustness | ok | None | 0.022105061569630286 | 0.00% backward steps (expected at this ripple) |
| bow_stress_2x | robustness | ok | None | 1.577366184878791 | 0.00% backward steps (expected at this ripple) |
| bow_stress_2x | robustness | ok | None | -0.18596591606190252 | 0.00% backward steps (expected at this ripple) |
| tau_aux_miscal_0.5pct | calibration | ok | False | 16.488929697828446 | tau_pct=0.5, vs.predicted=+0.35 cells |
| tau_aux_miscal_0.5pct | calibration | ok | False | 105.01476147208517 | tau_pct=0.5, vs.predicted=-0.23 cells |
| tau_aux_miscal_0.5pct | calibration | ok | False | 368.55166413188294 | tau_pct=0.5, vs.predicted=+0.19 cells |
| tau_aux_miscal_0.5pct | calibration | ok | False | 701.4317417866965 | tau_pct=0.5, vs.predicted=-0.20 cells |
| tau_aux_miscal_1pct | calibration | ok | False | 32.46669088642454 | tau_pct=1.0, vs.predicted=+0.35 cells |
| tau_aux_miscal_1pct | calibration | ok | False | 209.21755183249482 | tau_pct=1.0, vs.predicted=-0.23 cells |
| tau_aux_miscal_1pct | calibration | ok | False | 733.2614303933233 | tau_pct=1.0, vs.predicted=+0.19 cells |
| tau_aux_miscal_1pct | calibration | ok | False | 1396.1170108560693 | tau_pct=1.0, vs.predicted=-0.20 cells |
| tau_aux_miscal_2pct | calibration | ok | False | 63.95227911100619 | tau_pct=2.0, vs.predicted=+0.35 cells |
| tau_aux_miscal_2pct | calibration | ok | False | 414.5583446015069 | tau_pct=2.0, vs.predicted=-0.23 cells |
| tau_aux_miscal_2pct | calibration | ok | False | 1451.954205084863 | tau_pct=2.0, vs.predicted=+0.19 cells |
| tau_aux_miscal_2pct | calibration | ok | False | 2765.0556293161517 | tau_pct=2.0, vs.predicted=-0.20 cells |
| dispersion_beta2_off | known_limitation | ok | True | -0.38017597230587846 |  |
| dispersion_beta2_off | known_limitation | ok | True | 1.0991170772456405 |  |
| dispersion_beta2_on | known_limitation | ok | True | -0.38017597230587846 |  |
| dispersion_beta2_on | known_limitation | ok | True | 1.0991170772456405 |  |

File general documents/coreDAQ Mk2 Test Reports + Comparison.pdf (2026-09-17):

# core

I N S T R U M E N T A T I O N

Im Hasenleiser 10

69126 Heidelberg, Germany

core-instrumentation.com

C A L I B R AT I O N & T E S T R E P O R T
coreDAQ Mk 2 SN0001 | PASS · CAL_OK

DETECTOR · FRONT END
InGaAs · LOG

logarithmic, 20 mV/dB nominal

TIER · FIRMWARE
HIGH · HIGHBW

FW v1.6 · Fmax

1 MS/s · SYNC

CALIBRATION
1550.0 nm · 2026-09-17

Operator Ravi · 128-pt LUT

IDENTIT Y
UID 1D00…373530

calibration record verified

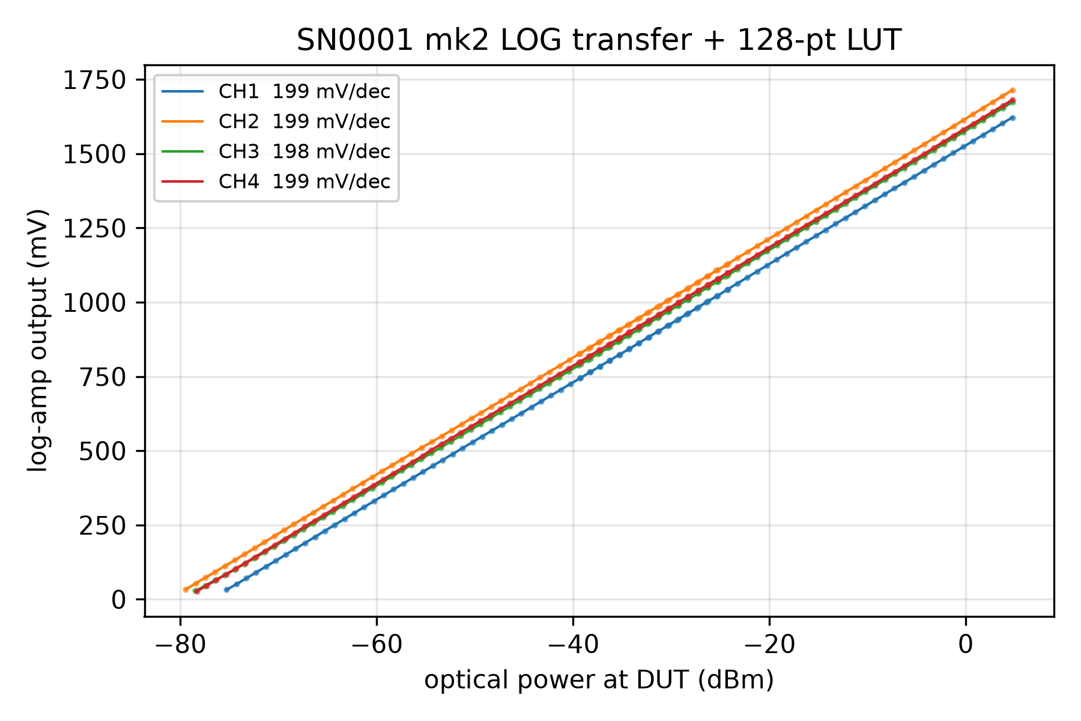
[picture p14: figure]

Fig.1 — Log-amp output vs optical power, CH1–CH4, with 128-pt LUT.

PER-CHANNEL LUT FIT

CH | SLOPE | PINT | R² | RESID RMS | RESID MAX | DARK | RANGE
1 | 19.87 mV/dB | 20.9 pW | 0.999990 | 6.8 mdB | 50.6 mdB | 10.4 mV | -75.3 … +4.7 dBm
2 | 19.93 mV/dB | 8.0 pW | 0.999965 | 6.2 mdB | 28.7 mdB | 9.3 mV | -79.4 … +4.7 dBm
3 | 19.84 mV/dB | 11.8 pW | 0.999947 | 7.5 mdB | 56.7 mdB | 7.4 mV | -78.5 … +4.8 dBm
4 | 19.90 mV/dB | 11.1 pW | 0.999988 | 9.7 mdB | 42.7 mdB | 11.8 mV | -78.3 … +4.8 dBm

METHODOLOGY

A 1550 nm laser is stepped through a calibrated attenuator in 1 dB

increments from +5 dBm down to -80 dBm and applied to each

channel in turn. Optical power at the unit is referenced to a NIST-

traceable power meter; below the meter's floor, power is derived

from the attenuator's calibrated transfer. Each point is the average

of repeated snapshots after settling. A monotonic 128-point lookup

table is fitted per channel and written to the device. Head 27.7 °C /

34.5 %RH during calibration.

STORED IN DEVICE

Monotonic 128-point calibration table per channel, fitted over -80.0

… +4.8 dBm, written to the unit's non-volatile calibration memory

together with a metadata record (serial, date, wavelength, tier, fit

summary) and the nominal InGaAs responsivity curve per head

(1000 – 1625 nm; 0.990 A/W at 1550 nm).

coreDAQ Mk 2 · SN0001 · InGaAs LOG · 2026-09-17 · info@core-instrumentation.com | 1 of 3

# core

I N S T R U M E N T A T I O N

Im Hasenleiser 10

69126 Heidelberg, Germany

core-instrumentation.com

C A L I B R AT I O N & T E S T R E P O R T
coreDAQ Mk 2 SN0002 | PASS · CAL_OK

DETECTOR · FRONT END
InGaAs · LOG

logarithmic, 20 mV/dB nominal

TIER · FIRMWARE
HIGH · HIGHBW

FW v1.6 · Fmax

1 MS/s · SYNC

CALIBRATION
1550.0 nm · 2026-09-17

Operator Ravi · 128-pt LUT

IDENTIT Y
UID 3C00…353937

calibration record verified

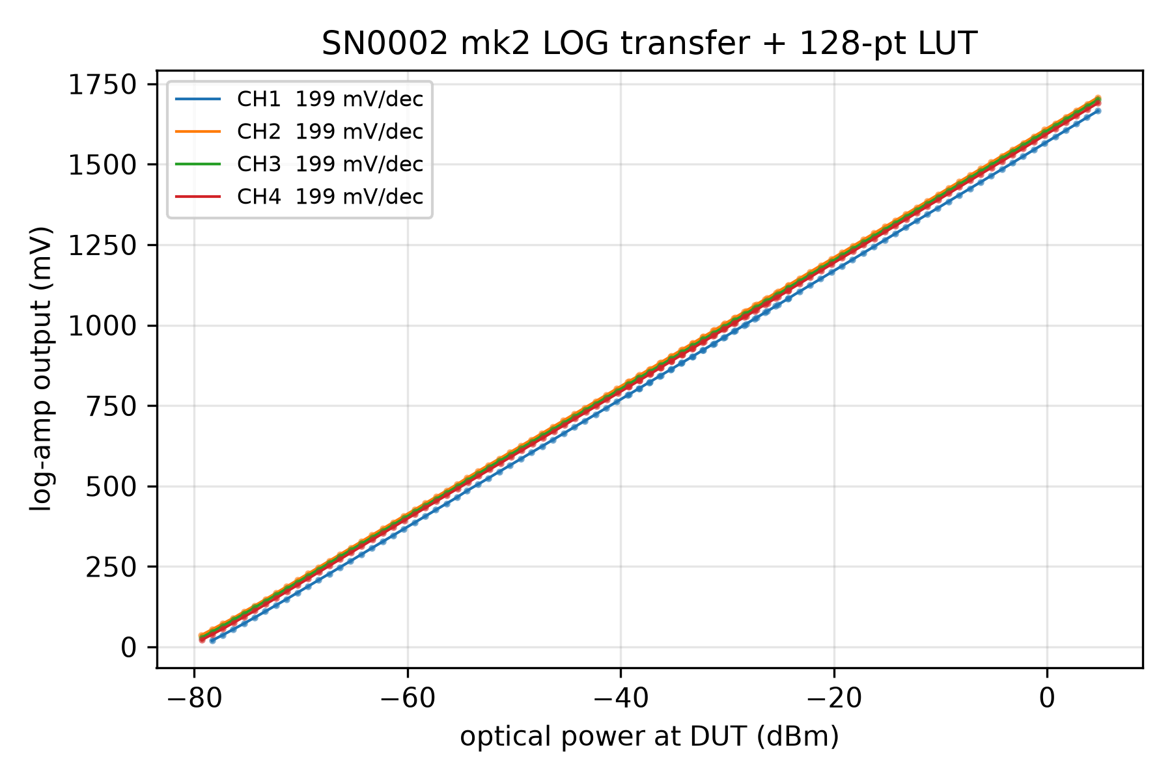
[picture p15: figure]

Fig.1 — Log-amp output vs optical power, CH1–CH4, with 128-pt LUT.

PER-CHANNEL LUT FIT

CH | SLOPE | PINT | R² | RESID RMS | RESID MAX | DARK | RANGE
1 | 19.89 mV/dB | 13.3 pW | 0.999972 | 5.4 mdB | 26.1 mdB | 10.1 mV | -78.3 … +4.7 dBm
2 | 19.93 mV/dB | 8.5 pW | 0.999981 | 5.9 mdB | 20.1 mdB | 13.6 mV | -79.3 … +4.7 dBm
3 | 19.91 mV/dB | 9.2 pW | 0.999975 | 5.2 mdB | 20.8 mdB | 7.0 mV | -79.3 … +4.7 dBm
4 | 19.91 mV/dB | 10.1 pW | 0.999982 | 7.8 mdB | 44.8 mdB | 8.9 mV | -79.3 … +4.7 dBm

METHODOLOGY

A 1550 nm laser is stepped through a calibrated attenuator in 1 dB

increments from +5 dBm down to -80 dBm and applied to each

channel in turn. Optical power at the unit is referenced to a NIST-

traceable power meter; below the meter's floor, power is derived

from the attenuator's calibrated transfer. Each point is the average

of repeated snapshots after settling. A monotonic 128-point lookup

table is fitted per channel and written to the device. Head 24.2 °C /

41.3 %RH during calibration.

STORED IN DEVICE

Monotonic 128-point calibration table per channel, fitted over -80.0

… +4.8 dBm, written to the unit's non-volatile calibration memory

together with a metadata record (serial, date, wavelength, tier, fit

summary) and the nominal InGaAs responsivity curve per head

(1000 – 1625 nm; 0.990 A/W at 1550 nm). Unit arrived uncalibrated

and now reports CAL_OK.

coreDAQ Mk 2 · SN0002 · InGaAs LOG · 2026-09-17 · info@core-instrumentation.com | 2 of 3

C O R E D A Q M K 2 · L O G A R I T H M I C F R O N T E N D | core-instrumentation.com

# Rise time&bandwidth vsphotocurrent

# LOWtier vs HIGH tier

Both SN0001 and SN0002 ship as HIGH tier (HIGHBW firmware, Fmax

1 MS/s). The logarithmic front end's small-

signal bandwidth is set by the photodiode current: at high currents the -3 dB point is fixed by the analog filter, at low

currents by the log-amp's input stage. The LOW tier caps the filter at 10 kHz and sampling at 100 kS/s; the HIGH tier

opens both to 150 kHz and 1 MS/s.

PHOTOCURRENT | OPTICAL POWER ¹ | LOW · BW (-3 DB) | LOW · RISE 10–90 % | HIGH · BW (-3 DB) | HIGH · RISE 10–90 %
1 mA | ≈ 1 mW · 0 dBm | 10 kHz | 35 µs | 150 kHz | 2.3 µs
100 µA | ≈ 100 µW · -10 dBm | 10 kHz | 35 µs | 150 kHz | 2.3 µs
10 µA | ≈ 10 µW · -20 dBm | 10 kHz | 35 µs | 150 kHz | 2.3 µs
1 µA | ≈ 1 µW · -30 dBm | 10 kHz | 35 µs | 150 kHz | 2.3 µs
100 nA | ≈ 100 nW · -40 dBm | 10 kHz | 35 µs | 150 kHz | 2.3 µs
10 nA | ≈ 10 nW · -50 dBm | 10 kHz | 35 µs | 150 kHz | 2.3 µs
1 nA | ≈ 1 nW · -60 dBm | 10 kHz | 35 µs | 50 kHz | 7 µs
100 pA | ≈ 100 pW · -70 dBm | < 10 kHz ² | > 35 µs ² | < 50 kHz ² | > 7 µs ²

¹ InGaAs, 0.99 A/W at 1550 nm. Bandwidth figures from the Mk 2 logarithmic-variant specification; rise time (10–90 %) computed as 0.35 / f-3 dB
for a

single-pole response. Sampling rate limits the resolvable rise time to ≥ 2 samples: 20 µs at 100 kS/s, 2 µs at 1 MS/s. ² Below 1 nA the log-amp input stage

dominates; bandwidth falls with photocurrent and is not specified.

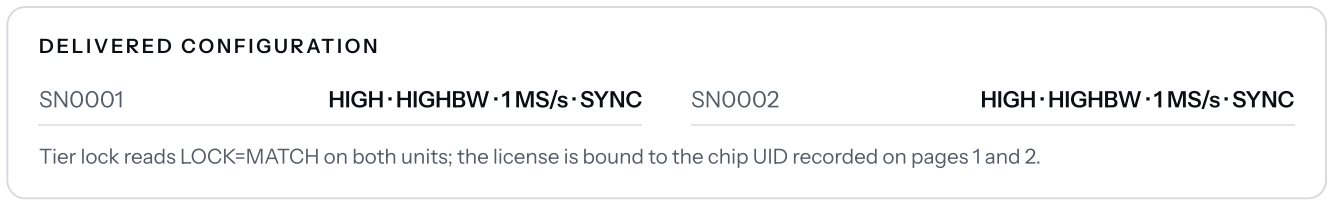
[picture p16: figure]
DELIVERED CONFIGURATION

SN0001 | HIGH · HIGHBW · 1 MS/s · SYNC | SN0002 | HIGH · HIGHBW · 1 MS/s · SYNC

Tier lock reads LOCK=MATCH on both units; the license is bound to the chip UID recorded on pages 1 and 2.

coreDAQ Mk 2 · Tier comparison · info@core-instrumentation.com | 3 of 3

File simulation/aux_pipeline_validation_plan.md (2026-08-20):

# Aux-pipeline validation — scenario matrix and findings

**For:** Carolina · **As of:** 2026-08-20 · Companion to `md files/followup_questions.md`

Harness: `simulation/validate_aux_pipeline.py`. Runs `simulation/simulate_aux_data.py`
(`simulate(a)`) → `process_reflectogram_aux.py` (`process(a)`, stays at the
repo root — it also processes real bench data) across a matrix of scenarios
and writes `simulation/results/aux_validation_<date>/summary.csv` +
`summary.md`. Each scenario gets its own subfolder with `sim.npz` and the
usual `_reflectogram.csv/.png`, so any flagged case can be re-run by hand
(note the explicit channel args — the simulator writes Ch1/Ch2=aux,
Ch3/Ch4=meas, not the real-hardware interleaved default):

```bash
python process_reflectogram_aux.py simulation/results/aux_validation_2026-08-20/<name>/sim.npz \
    --dl 4 --aux-a 1 --aux-b 2 --meas-a 3 --meas-b 4
```
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

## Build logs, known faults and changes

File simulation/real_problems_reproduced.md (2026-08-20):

# Reproducing today's real bench problems in simulation

**As of:** 2026-08-20. Uses the new `--internal-reflectors`, `--ghosts`,
`--aux-leak-db`, `--saturation-frac`, `--saturation-ceiling` flags added to
`simulation/simulate_aux_data.py` specifically to test the two biggest
mysteries from today's real scans (`logs/2026-08-20.md`): the persistent
587mm/518mm peaks and the detector-saturation-driven monotonicity failures.

## 1. The 587mm/518mm "ghost" peaks

**Mechanism modeled:** two independent, always-present fixed reflectors
inside the instrument (587mm at ~0 dB, 518mm at ~-20 dB — matching what six
real scans converged on), plus **multipath/double-bounce ghosting**: light
that partially reflects off tone *i*, continues, partially reflects off tone
*j*, and returns, travels the delay **sum** τ_i+τ_j — the standard mechanism
for "sum-position" ghosts in OFDR/OTDR. Amplitude ≈ product of the two field
amplitudes. The aux tone is included in the ghost pool too (at a tunable,
reduced "leak" coupling), since the real data showed aux-involving sum peaks
as well, implying imperfect isolation between the aux and measurement paths.

**Command:**
```bash
python simulation/simulate_aux_data.py --points 1000000 --speed 50 --lam0 1520 \
    --dl 4.24 --reflectors 1.062:-13 --internal-reflectors 0.587:0 0.518:-20 \
    --ghosts --aux-leak-db -8 --out sim_ghosts.npz
python process_reflectogram_aux.py sim_ghosts.npz --dl 4.24 \
    --aux-a 1 --aux-b 2 --meas-a 3 --meas-b 4 --zmax 4.5 --peak-floor-db -50
```

**Result — every peak found matches a fundamental or a pairwise sum, at the
predicted dB level:**

| Found (mm) | dB | Identity | Predicted |
|---|---|---|---|
| 518.0 | -19.8 | fundamental: internal reflector B | -20.0 |
| 587.0 | 0.0 | fundamental: internal reflector A | 0.0 |
| 1036.0 | -39.9 | 518+518 (2nd harmonic of B) | -40.0 |
| 1062.0 | -13.1 | fundamental: DUT fiber | -13.0 |
| 1105.0 | -20.2 | 587+518 (A+B) | -20.0 |
| 1174.0 | -0.6 | 587+587 (2nd harmonic of A) | 0.0 |
| 1580.0 | -33.0 | 518+1062 (B+fiber) | -33.0 |
| 1649.0 | -12.8 | 587+1062 (A+fiber) | -13.0 |
| 2124.0 | -26.4 | 1062+1062 (2nd harmonic of fiber) | -26.0 |
| 2638.0 | -28.4 | 518+2120 (B+aux) | -28.0 |
| 2707.0 | -8.2 | 587+2120 (A+aux) | -8.0 |
| 3182.0 | -21.4 | 1062+2120 (fiber+aux) | -21.0 |
| 4240.0 | -16.7 | 2120+2120 (2nd harmonic of aux) | -15.9 |

This is qualitatively and quantitatively the same pattern as the real data:
main+fiber sums, aux+main sums, 2nd harmonics, all present, all at
roughly the product-of-amplitudes dB level.

**Why this occurs:** a real, discrete partial reflector fixed inside the
instrument (not yet physically localized — candidates per the hardware:
a connector interface in the LO arm, the circulator, or the eVOA) sits in
series with the DUT and the return path. Because it's a *partial* reflector
(not total), a fraction of the light double-bounces between it and every
other reflector in the system (including the aux's own return path, if
isolation there isn't perfect), producing the sum-delay ghosts.

**How to remove it:**
- **Kill (or weaken) the fixed reflector itself.** Ghost amplitude scales
  with the *product* of the two reflectivities — since the 587mm reflector
  participates in nearly every ghost family, suppressing it (index-matching
  gel, a better-polished connector, an isolator at the suspect interface)
  collapses most of the ghost forest at once, not just one peak.
- **Localize it the same way the 6-32cm band was killed in the old setup**
  (`HANDOVER.md` §5's method): swap/bypass one component at a time between
  the circulator and the coupler, re-scan, and see which change makes the
  587mm peak vanish. The already-run no-fiber control test proved it's
  internal, not DUT-related — the next step is component-by-component
  isolation, not another full-fiber scan.
- **Improve aux/measurement isolation** if the aux-involving ghosts
  (2707mm, 2638mm, 3182mm here) turn out to matter in practice — these
  point at optical crosstalk between the two interferometers, not the
  587mm reflector itself.

## 2. Detector saturation -> monotonicity failure

**Mechanism modeled:** the first `--saturation-frac` of samples get each
channel hard-clipped to `--saturation-ceiling` of its own (unsaturated)
range — a plausible model of an ADC/detector ceiling being hit at the start
of the sweep, exactly as found 2026-08-19 (first ~10nm / ~20% of every real
scan).

**Command:**
```bash
python simulation/simulate_aux_data.py --points 1000000 --speed 50 --lam0 1520 \
    --dl 4.24 --reflectors 0.587:0 1.062:-13 --saturation-frac 0.2 \
    --saturation-ceiling 0.12 --out sim_saturation.npz
```

**Result, replicating Carolina's own diagnostic method (balanced Ch1/Ch2 ->
analytic signal -> unwrap -> backward-step fraction) directly on the
simulated aux channels:**

```
full scan backward-step fraction: 5.312%
  saturated (first 20%) region:   26.561%
  clean (remaining 80%) region:   0.000%
```

Backward phase steps appear **exclusively** in the saturated region and
**zero** elsewhere — the identical spatial signature found in the real data
("almost all backward steps fall in the first ~16% of the sweep... zero
afterward"). This confirms the mechanism: saturation-induced amplitude
clipping distorts the Hilbert-transform-derived instantaneous phase enough
to make it momentarily run backwards, exactly where the detector is
saturated and nowhere else.

Two side-effects also reproduced:
- `process_reflectogram_aux.py`'s own contrast diagnostic misreads this as
  **polarization fading** ("aux contrast drops somewhere") — a real,
  slightly misleading overlap worth knowing about: a low `amp_min` doesn't
  automatically mean polarization: check WHERE in the sweep it happens
  first.
- Despite the locally severe phase corruption, final reported positions
  stayed accurate in this run (`resample_on_aux()`'s
  `np.maximum.accumulate` clamp absorbs the backward excursions into the
  first few resampled points rather than smearing them across the whole
  axis) — meaning the corruption can be present and briefly invisible in
  the final PASSED/FAILED verdict while still being real and worth fixing
  before trusting a bow/ripple measurement from the same region.

**Why this occurs:** confirmed already in the real investigation as
detector/interferometer behavior at sweep start, not the laser (a direct
laser-only reference scan showed no equivalent ramp) — likely input-range
autoranging or settling at the very start of acquisition.

**How to remove it:**
- **Software (already applied, costs ~24% resolution):** trim the affected
  samples, exactly as done 2026-08-19 (`_trimmed1530.npz`). Confirmed here:
  the "clean" region alone has 0% backward steps.
  `simulate_aux_data.py --saturation-frac` lets you size how much margin a
  given trim fraction actually buys back, before touching the bench.
  - **Hardware (real fix, not yet tried):** per `HANDOVER.md`'s existing
  "fixed power range on every channel" rule — check whether the CoreDAQ's
  input range is set to accommodate whatever power spike happens at sweep
  start (or add a brief settling delay before recording), rather than
  discovering it after the fact via trimming every scan.

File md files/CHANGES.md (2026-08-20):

# Findings and Corrections

## Measurement: aliased

| Quantity | Value |
|---|---|
| Step size δλ | 0.9998 pm |
| Bandwidth | 49.908 nm = 6.268 THz |
| Resolution δz = c/(2 n_g B) | 16.3 µm |
| **Nyquist range** λ²/(4 n_g δλ) | **40.66 cm reflector distance** (81.3 cm OPD) |
| Reflectogram peak | 34.8 cm — not a peak, a broad hump |
| Energy in the top 20% before Nyquist | **68%** |

Ch1 and Ch2 correlate at **−0.93** (out-of-phase coupler ports), the sum
Ch1+Ch2 is nearly constant (σ/µ = 0.10), the difference carries the full
fringe (σ/µ = 0.52). So the signal is **real interference with full
modulation** — not noise. It's simply beyond Nyquist.

Best single-target hypothesis from three independent methods (first-order
folding, chirp slope across sub-bands, dechirped NUDFT scan):
**OPD ≈ 92 cm, corresponding to a 46 cm reflector distance.** That's ~13%
beyond the limit. The number only becomes trustworthy with a sweep at
δλ ≤ 0.5 pm.

## Bugs in reflectometer_v1_buggy.py (formerly fft_reflectometer.py)

*(2026-08-18: this script and its corrected sibling `reflectometer_v2_fixed.py`
were deleted — the bug list below is the reason they existed in the first
place, and it's preserved here along with git history; keeping the actual
buggy code around had no further value.)*

1. **Last sample is garbage.** `Wavelength[-1] = 1519.95` (jumps back to the
   sweep start). This turns `np.mean(np.diff(wavelength))` into **2.40e-6 nm**
   instead of 1e-3 nm — the frequency axis ends up scaled wrong by a factor
   of **416**. → discard non-monotonic points, use `np.median` instead of
   `np.mean`.

2. **Wrong conversion in the λ branch (default).** `length_nm = peak_frequency
   / refractive_index` only holds in the wavenumber branch. In the λ domain,
   f = n_g·ΔL/λ², so **ΔL = f·λ²/n_g**. The λ² ≈ 2.39e6 nm² factor is missing.

3. **Missing factor of 2.** For a reflection measurement, the reflector
   distance is OPD/2.

4. **No DC/envelope removal.** `argmax` over `freq > 0` picks up bin 1–2 (the
   laser power envelope) instead of the actual signal. Result from the old
   version: 5.7e-9 m and 1.3e-2 m — both artifacts.

5. **No window.** Without a Hann window, sidelobes smear weak reflections.

6. **Ch2 unused.** `(Ch1−Ch2)/(Ch1+Ch2)` removes the power envelope exactly
   and doubles the fringe contrast. Free improvement.

7. **No Nyquist check.** The script never warned that the measurement was
   outside the valid range.

8. `plt.xlim(0, 3)` suggests a 3 m measurement range. The real range is
   40.7 cm.

9. The reported wavelengths are **rounded** to 1 pm (step sequence 0/1/2 pm).
   For the phase, an ideally uniform grid (`linspace(λ_0, λ_N, N)`) is the
   better assumption — the rounded values add up to ±0.5 pm of jitter, which
   at OPD ≈ 1 m already means ~1.9 rad of phase error.

## Next step

δλ = 0.5 pm → range 81 cm, 100,000 points.
δλ = 0.2 pm → range 2.03 m, 250,000 points (safety factor 2 for 1 m).

Resolution stays at 16.3 µm in all cases — it only depends on bandwidth.

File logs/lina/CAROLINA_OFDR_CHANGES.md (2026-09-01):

# Changes on `carolina-ofdr` vs. upstream `main`

This document describes everything that has been changed on the
`carolina-ofdr` branch relative to the original AkheLab codebase
(`Akhetonics/AKHExperiment`, `main`). It exists because this account does
not have push access to the upstream repo, so these changes currently only
live on this branch / on a personal fork.

**Relocated:** the plain EXFO laser window (`exfo_window.py`) has been
reverted to its original, pre-this-branch state. Everything described below
(Response Sweep's coreDAQ-LIN support, the Y-axis toggle, manual LIN
arming, settle margin) now lives instead in a new, separate "OBR"
instrument type — `Interface/OBR.py` (`OBR` superclass, `Lina` concrete
class: an EXFO + coreDAQ-LIN pairing) and
`LabGUI/dashboards/instruments/lina_window.py` (`LinaWindow`, a copy of the
old EXFO window preselected to that pairing). The plain "Lasers" category
now shows the unmodified upstream EXFO window again; the new "OBR" category
shows Lina. The technical write-up below still describes the original work
accurately — read `exfo_window.py`/`Interface/Lasers.py` as
`lina_window.py`/`Interface/OBR.py` throughout. `Interface/Lasers.py` itself
was **not** reverted (§4's `trig_out()` fix is a generic, backward-compatible
driver improvement that Lina also depends on).

All changes so far touch the EXFO tunable-laser "Response Sweep" workflow
and its coreDAQ power-meter integration, plus one supporting fix in the
EXFO SCPI driver. Three files were originally affected:

- `Interface/Lasers.py` (kept, unchanged by the relocation)
- `LabGUI/dashboards/instruments/exfo_window.py` (reverted; logic moved to
  `lina_window.py`)
- `.vscode/settings.json`

Commits (oldest first): `ad7b8f0`, `f4adc55`, `4eaf141`, `965f64f` (the last
one removed the anti-saturation-range checkbox mentioned in §5, keeping
only the settle-margin field).

---

## 1. Made coreDAQ-1 (LINEAR variant) work in Response Sweep at all

**Problem:** Response Sweep's coreDAQ capture path only supported the
custom-stepper coreDAQ variant (e.g. coredaq-2, LOG frontend), which arms
the device in STEPPED trigger mode — one ADC sample per EXFO trigger edge,
re-arming after each one. That mode requires coreDAQ firmware v4.3+ and
only exists on the stepper-capable units. The standard LINEAR coreDAQ (e.g.
coredaq-1) doesn't support per-edge STEPPED arming and doesn't need
firmware v4.3, but the code always used STEPPED mode regardless of which
variant was selected.

**Fix (`exfo_window.py`, `_CoreDAQSweepWorker`):** the worker now branches
on the coreDAQ's PM_config `variant` field (`LINEAR` vs `LOG`) via a new
`stepped` flag:

- `stepped=True` (LOG/custom-stepper units, unchanged behavior): one EXFO
  trigger edge per wavelength step, coreDAQ re-arms after each sample, the
  real per-edge wavelength table is read back from the laser afterward
  (`get_pulse_wavelengths`).
- `stepped=False` (LINEAR units, e.g. coredaq-1, new): a single trigger
  edge starts the capture; the coreDAQ then free-runs continuously at its
  own sample rate for the whole sweep. There is no per-edge wavelength
  table in this mode, so the wavelength axis is reconstructed linearly over
  the sweep's actual (readback) start/stop wavelength.

### Two firmware-interaction bugs found and fixed while wiring this up

1. **`finalize_capture()` wiping a completed capture.** `finalize_capture()`
   sends an ACQ STOP to the device. When the capture had already reached
   the firmware's DONE state (4) on its own, sending STOP anyway reset the
   stored frame count to 0 instead of being a harmless no-op — silently
   destroying a buffer that had fully filled. Fixed by querying the
   acquisition state first and only calling `finalize_capture()` when the
   capture is *not* already DONE.
2. **`captured_frames()` silently reading as 0 on older firmware.** This
   query (`FRAMES?`) is itself gated behind firmware v4.3+. On older
   firmware it fails and the PowerMeters.py wrapper swallows the exception,
   returning `-1` — which looked identical to "0 frames captured" even
   though the SDRAM buffer was genuinely full. Fixed for the LINEAR/
   continuous path: since a DONE state in that mode means "all `n_frames`
   armed were collected" by construction, the code now uses the originally
   armed `n_frames` directly instead of re-querying the device.

---

## 2. Y-axis linear/log toggle for the Response Sweep plot

**`exfo_window.py`:** added two buttons under the Response Sweep plot to
switch the Y-axis between linear and logarithmic scale. The selection
persists across re-plots (re-running a sweep, or replaying the same sweep
after a Y-axis change, keeps the chosen scale instead of resetting to
linear).

---

## 3. Manual sample-count / sample-rate arming for LINEAR coreDAQ

**Problem:** in continuous/LINEAR mode there's no per-edge trigger table,
so the frame count has to be derived some other way. Originally it was
always derived from the EXFO's reported sweep duration × sample rate —
with no way to request an exact, fixed number of samples per channel (e.g.
for a fixed ~1,000,000-point-per-channel OFDR capture, independent of how
long the sweep happens to take).

**Fix (`exfo_window.py`):** when a LINEAR coreDAQ (e.g. coredaq-1) is
selected as the capture device, the UI now exposes direct **Samples/channel**
and **Sample-rate (Hz)** controls, plus a live capture-duration estimate
that warns if it looks mismatched against the actual configured sweep time.
Device buffer sizing note surfaced in the tooltip: 32 MB SDRAM ≈ 16.7M
points on 1 channel, ≈ 4.2M points/channel across 4 channels — so the
default of ~1,000,000 points/channel is comfortably within range.

(A short-lived standalone script, `carolina/ofdr.py`, was written first to
prototype this single-trigger-edge + continuous-capture approach outside
the GUI, then removed once the same functionality was integrated directly
into Response Sweep's manual-arming path above.)

---

## 4. Real SCPI trigger in/out control for SWEEP mode (`Interface/Lasers.py`)

**Problem:** `EXFO.trig_out()` only supported `mode="PULSE"` in a way that
sent SCPI commands (`SOUR:SWE:SYNC:*`, `SOUR:WAV:SWE:SYNC:SAMP`,
`SOUR:OPT:BCOM:STAT`) that do not appear anywhere in the T200S SCPI Command
Reference and almost certainly originate from a different EXFO laser
model. `mode="SWEEP"` existed but only toggled a trigger-type SCPI value
with no way to actually configure trigger source (external vs. immediate)
or the trigger-out BNC signal independently.

**Fix:** `trig_out()` gained explicit parameters for the SWEEP path, each
mapped to a command that *is* documented in the T200S SCPI Command
Reference:

- `trigger_in: bool` → `TRIGger[:SEQuence]:SOURce EXTernal|IMMediate`
  (p.133) — `True` arms the sweep to start from the external Trig In BNC,
  `False` starts it manually/by software.
- `trigger_out: bool` → `OUTPut:SYNChronization[:STATe] ON|OFF` (p.95) —
  the Trig Out BNC goes high for the duration of the sweep.
- `out_type` / `sampling_pm` (Window vs. Pulse trigger-out shape, and
  per-step sampling interval): **not supported remotely** — no matching
  command exists in the SCPI reference for this instrument. These
  parameters are accepted for API compatibility but are logged as a
  warning and not sent to the device; they must be set on the laser's own
  touchscreen.
- After configuring, `trig_out()` now reads back the device's error queue
  (`SYST:ERR?`, via a new `get_error()` helper) and raises if the laser
  rejected the configuration, instead of failing silently.

The original `mode="PULSE"` code path (used by the STEPPED coreDAQ sweep
workers) was left functionally unchanged — its SCPI commands are flagged
as unverified/likely wrong in a docstring, but not touched, so as not to
break the existing STEPPED-mode callers without a documented replacement.

**`exfo_window.py` UI side:** the "Trigger Output" panel gained real
**Trigger in** / **Trigger out** checkboxes and **Window** / **Pulse**
radio buttons (mirroring the laser's own front-panel "Sweep triggers"
options), wired to the corrected `trig_out()` call above; the Window/Pulse
choice is visibly marked as "set on the laser touchscreen — not remotely
controllable" wherever it can't actually be sent over SCPI.

---

## 5. coreDAQ-1 saturation in the first ~10 nm of a sweep

**Symptom:** on coreDAQ-1 (LINEAR), the first ~10 nm of every Response
Sweep showed the channel pinned in over-range / saturation.

**Investigation:**

- Added an **"Anti-saturation range"** checkbox (LINEAR coreDAQ only):
  when checked, disables autorange and forces every armed channel to
  manual TIA range index 0 (5 mW full-scale, the least sensitive available
  range) before arming.
- Tested with the checkbox on — the channel still saturated. This ruled
  out a range/gain misconfiguration: range index 0 is already the most
  power-tolerant range the LINEAR frontend has, so if that still trips, no
  range/gain setting can fix it — the over-range trip point is confirmed
  (via the `py-coreDAQ` documentation) to be a **fixed hardware threshold**
  on the ADC voltage (`|V| > 4.2 V`), not adjustable in Watts or Volts.
- With no EDFA or variable optical attenuator in the optical path (direct
  laser → coreDAQ), the real cause was identified as the **laser's own
  output-power settling transient** right as a continuous sweep starts
  moving — a fixed *wavelength* distance of ringing/overshoot, not a
  power-level or gain problem.

**Fix — "Settle margin (nm)" (LINEAR coreDAQ only, default 10 nm):**
the *physical* EXFO sweep is started this many nm before the user's
requested start wavelength (in whichever direction is "before" for that
sweep's direction), so the laser's settling transient plays out before it
reaches the wavelength range the user actually asked for. The coreDAQ
still captures through that pre-roll — sized automatically into the
existing frame-count calculation — and after capture, the pre-roll samples
(anything before the originally requested start wavelength) are cropped
back out of the result. The returned sweep therefore still spans exactly
the user's requested start/stop, but without the settling artifact at the
front.

Both the anti-saturation-range checkbox and the settle-margin field are
independent, opt-in controls (both default to their current/no-op state
except settle margin, which defaults to 10 nm) — they don't change
behavior for the STEPPED (LOG-variant) coreDAQ path at all.

---

## 6. Misc

- `.vscode/settings.json`: default Python environment manager switched
  from `ms-python.python:venv` to `ms-python.python:system` (editor-local
  preference, not functional code).

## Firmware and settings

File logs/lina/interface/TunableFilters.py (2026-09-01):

"""
Tunable optical filters.

TOF1550 — Thorlabs C-band digital tunable Gaussian bandpass filter.

Protocol (User Guide TTN356097-D02, §4.2): FTDI virtual COM port,
115200 8N1, no flow control. Commands are SCPI-like but abbreviated, one per
write, terminated with <NL>; replies are terminated with <CR> and start with
"OK" on success or "Err: ..." on failure. Multiple commands in one string are
NOT accepted, and exponential notation in parameters is NOT accepted.

Command set is small: WAVElength? / WAVElength X (nm), WAVElength:STep? /
WAVElength:STep X (pm), WAVElength:INcrease / :DEcrease, CHANnel? / CHANnel X
(ITU). There is no motion/settled status query, so set_wavelength() waits a
fixed settle time (``settle_s``, from config) and verifies by readback.
"""

import json
import re
import time
from pathlib import Path
from typing import Optional

import serial
import serial.tools.list_ports

# This driver lives under lina/ rather than Interface/, so it imports the base
# class from the repo's Interface package explicitly (the relative-import
# fallback used by the drivers inside Interface/ cannot work from here).
try:
    from Interface.LabDevice import LabDevice
except ImportError:                      # running with Interface/ on sys.path
    from LabDevice import LabDevice


_TF_CFG_CANDIDATES = [
    Path(__file__).resolve().parent / 'config' / 'TunableFilter_config.json',
    Path(__file__).resolve().parent / 'TunableFilter_config.json',
]


def _resolve_tf_config() -> Path:
    for p in _TF_CFG_CANDIDATES:
        if p.exists():
            return p
    raise FileNotFoundError(
        "TunableFilter_config.json not found. Tried:\n" +
        "\n".join(str(p) for p in _TF_CFG_CANDIDATES)
    )


class TOF1550(LabDevice):
    """Thorlabs TOF1550 digital tunable C-band bandpass filter.

    Specified 1527–1567 nm tuning range, 0.21 nm passband at -3 dB, <32 pm
    absolute setting error, ±8 pm repeatability — narrow and accurate enough
    to be used as a wavelength marker in a laser sweep.
    """

    WL_MIN_NM = 1527.0
    WL_MAX_NM = 1567.0

    def __init__(self, name: str = "tof1550-1", config_path: Optional[str] = None,
                 port: Optional[str] = None):
        self._baudrate = 115200
        self._timeout = 1.0
        self._settle_s = 1.0
        cfg_port = None
        try:
            cfg_path = Path(config_path).expanduser().resolve() \
                if config_path else _resolve_tf_config()
            with open(cfg_path) as fp:
                cfg = json.load(fp)
            dev_cfg = cfg.get('TOF1550', {}).get(name, {})
            cfg_port = (dev_cfg.get('serial_id') or '').strip() or None
            self._baudrate = int(dev_cfg.get('baudrate', self._baudrate))
            self._timeout = float(dev_cfg.get('timeout_s', self._timeout))
            self._settle_s = float(dev_cfg.get('settle_s', self._settle_s))
        except Exception:
            pass   # no config — port must be passed explicitly

        self.port = port or cfg_port
        if self.port and self.port.upper() in ('AUTO', 'NA', 'NONE'):
            self.port = None
        self.ser: Optional[serial.Serial] = None
        super().__init__(name, serial_id=self.port or 'AUTO')

    # ---------- discovery ----------

    @staticmethod
    def find_ports() -> list:
        """Candidate COM ports: the unit enumerates through the generic FTDI VCP
        driver (VID 0x0403, descriptor "USB Serial Port"), so it is NOT
        distinguishable from any other FTDI adapter by descriptor alone, and it
        has no identity command. Pin the port in TunableFilter_config.json;
        this list is only a fallback shortlist."""
        return [p.device for p in serial.tools.list_ports.comports()
                if p.vid in (0x0403, 0x1313)]

    # ---------- connection management ----------

    def open(self):
        if self.port is None:
            candidates = self.find_ports()
            if not candidates:
                raise ConnectionError(
                    "No Thorlabs FTDI COM port found for the TOF1550. Set "
                    "'serial_id' in TunableFilter_config.json to its COM port.")
            self.port = candidates[0]
            self.logger.info(f"Auto-selected {self.port}")
        try:
            self.ser = serial.Serial(
                port=self.port, baudrate=self._baudrate,
                bytesize=serial.EIGHTBITS, parity=serial.PARITY_NONE,
                stopbits=serial.STOPBITS_ONE, timeout=self._timeout,
                write_timeout=self._timeout,
                rtscts=False, dsrdtr=False, xonxoff=False)
        except serial.SerialException as ex:
            self.logger.error(f"Could not open {self.port}: {ex}")
            raise ConnectionError(f"Could not open {self.port}") from ex
        try:
            self.ser.reset_input_buffer()
            self.ser.reset_output_buffer()
        except Exception:
            pass
        wl = self.get_wavelength()
        self.logger.info(f"Connected on {self.port} @ {self._baudrate} bps, "
                         f"center {wl:.3f} nm")
        return True

    def close(self):
        if self.ser is not None:
            try:
                self.ser.close()
            except Exception as ex:
                self.logger.warning(f"Error closing port: {ex}")
            self.ser = None
            self.logger.info("Disconnected")

    # ---------- I/O primitives ----------

    def _send(self, command: str) -> str:
        """Send one <NL>-terminated command, return the reply with the leading
        "OK" stripped. Raises RuntimeError on an "Err: ..." reply."""
        if self.ser is None:
            raise RuntimeError(f"{self.id}: not connected")
        self.ser.reset_input_buffer()
        self.ser.write((command.strip() + "\n").encode("ascii"))
        self.ser.flush()
        # The manual specifies <CR>-terminated replies; the unit actually sends
        # <LF> ("OK. The center wavelength is 1550.000 nm.\n").
        raw = self.ser.read_until(b"\n").decode("ascii", "replace").strip()
        if not raw:
            raise RuntimeError(f"{self.id}: no reply to {command!r}")
        if raw.lower().startswith("err"):
            raise RuntimeError(f"{self.id}: {raw} (command {command!r})")
        return re.sub(r'^\s*OK[.:]?\s*', '', raw).strip()

    @staticmethod
    def _first_float(reply: str) -> float:
        m = re.search(r'[-+]?\d+(?:\.\d+)?', reply)
        if not m:
            raise ValueError(f"No number in reply {reply!r}")
        return float(m.group(0))

    # ---------- wavelength ----------

    def get_wavelength(self) -> float:
        """Current filter center wavelength in nm."""
        return self._first_float(self._send("WAVElength?"))

    def set_wavelength(self, wavelength_nm: float, wait: bool = True) -> float:
        """Set the center wavelength (nm) and return the value read back.
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

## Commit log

2026-08-12 Add corrected OFDR evaluation and document aliasing findings
    The existing fft_reflectometer.py reports 5.7e-9 m for the test sweep.
    Four defects cause this:
    - The EXFO appends a non-monotonic final sample (1519.95 nm) that wraps
    to the sweep start. np.mean(np.diff(wavelength)) becomes 2.4e-6 nm
    instead of 1e-3 nm, scaling the frequency axis by a factor of 416.
    - In the wavelength-domain branch, length = f / n_g omits lambda^2.
    The correct relation is dL = f * lambda^2 / n_g.
    - The round-trip factor 2 is missing: reflector distance is OPD / 2.
    - Without envelope removal, argmax over freq > 0 picks up the laser
    power envelope in bins 1-2 rather than the fringe signal.
    fft_reflectomet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
2026-08-20 neu
    Keep raw EXFO JSON scans local-only (gitignore raw_data/*.json) -- the
    1M-datapoint sweeps run ~150MB each, over GitHub's 100MB limit. Only the
    trimmed .npz derivatives and results/ outputs are tracked going forward.
    [2026-08-19_1miodatapoints_reflectogram_ch1ch3meas.csv, 2026-08-19_1miodatapoints_reflectogram_ch1ch3meas_zoom_reflectogram.csv, 2026-08-19_1miodatapoints_refle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]
2026-08-20 Merge aux-pipeline validation harness with real-hardware channel-pairing fix; reorganize into simulation/
    Rebuilt the harness's refactor (simulate()/process() extraction, --beta2
    dispersion flag, Nyquist aliasing fold-fix) on top of the channel-pairing
    correction pulled from origin (Ch1/Ch3=aux, Ch2/Ch4=measurement,
    interleaved -- confirmed against real hardware 2026-08-19). Also fixed a
    numpy-bool counting bug in the harness's own pass/fail summary.
    Moved all simulation-specific files (simulate_aux_data.py,
    validate_aux_pipeline.py, aux_pipeline_validation_plan.md, validation
    results) into a new simulation/ folder; process_reflectogram_aux.py stays
    at the root since it processes both real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
    [summary.csv]
2026-08-20 Simulate today's two real bench mysteries: 587mm/518mm ghost peaks and saturation-driven monotonicity failure
    Added --internal-reflectors/--ghosts/--aux-leak-db (fixed reflectors +
    multipath double-bounce ghosting) and --saturation-frac/--saturation-ceiling
    (detector clipping at sweep start) to simulate_aux_data.py, opt-in and
    default-off.
    Ghost simulation: every peak the pipeline found matched a fundamental or a
    pairwise delay-sum ghost at the predicted dB level, reproducing the same
    pattern found across six real scans today (main+fiber sums, aux+main sums,
    2nd harmonics).
    Saturation simulation: replicating Carolina's own backward-step diagnostic
    on the simulated aux channel gave 26.6% ba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
2026-08-20 Localize the 587mm fixed reflector to the connector slot; settle-margin firmware fix removes the saturation trim
    - Three no-fiber control scans (Thorlabs -> normal connector #1 -> normal
    connector #2) show the ~587mm-family peak's position tracks the physical
    path length of whichever connector occupies that slot: 587.8mm (Thorlabs)
    -> 467.1mm (connector #1, unaffected by fiber cleaning) -> 589.7mm
    (connector #2, back in the original family). Updated HANDOVER.md section 2.
    - New akhelabs acquisition-software settle-margin fix (exfo_window.py)
    eliminates the ~10-13nm detector-saturation transient at sweep start;
    verified on a new scan (no trim needed) and confirmed the predicted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
2026-08-20 Note in log: why the ghost fiber peaks sit at fixed-offset positions, not scaled ones
    Sum-of-delays (double bounce with the 587mm reflector) vs. a calibration
    error would show up differently: a fixed additive offset (~587-680mm)
    across both fibers, not a multiplicative scale factor -- that's the
    signature that distinguishes the two.
2026-08-20 Add supervisor progress report for KW34; regenerate fiber-comparison plot with self-referenced inferred lengths
    Report in george/progressreport_kw34/ summarizes the aux-referenced
    distance axis, the fixed connector reflection and its double-bounce
    effect on the other peaks, the sweep-start saturation fix, and the
    AkheLab software extension for 1M samples/channel.
    The comparison plot now labels every fiber (including the 3m one) by
    its calculated peak-minus-connector length instead of the tape-measured
    value, using each scan's own dominant peak as its connector reference.
2026-09-11 @ progress report kw37 + optical netlist extraction
    Progress report for the supervisor on the first HHI chip measurements
    (george/progressreport_kw37/) with five figures.
    New tool tools/gds_netlist_reflectors.py: builds an optical netlist from
    the GDS (waveguide polygons + HHI component ports on layer 235/0) and
    returns the path length from any edge coupler to every component
    interface in the chip. Validated on the top loopback pair, where it
    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
    [netlist_reflectors.csv]
2026-09-11 retract the "independent n_g" result; make the identifier honest
    New tool tools/identify_chip_scan.py: takes a raw HHI chip scan, derives
    tau_aux from the scan's own aux pair, builds the reflectogram, anchors the
    internal reference and facet A via the pigtail-length family, and checks
    the peaks against the optical netlist -- printing which component each peak
    corresponds to and the n_g each one implies.
    Building it surfaced the test I had skipped: sweeping n_g from 3.0 to 4.0
    leaves the best-fit score flat (7.3..19.3, maximum at n_g = 3.02, no peak
    near 3.48). A flat score means the data does not contain the information.
    The three b2 component interfaces that appeared to confirm n_g = 3.479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
    [demo_b2_identified.csv]
2026-09-14 one-command mode for identify_chip_scan.py
    --out is now optional: without it the output prefix becomes
    results/<date>/<scan name>, with the date taken from the scan filename
    (YYYY-MM-DD prefix) and falling back to today. --from-csv is gone as
    well, a .csv input is recognised by its extension. A single invocation
    therefore writes the reflectogram (csv + png) and the identification
    (csv + png) into the correct results folder:
    python tools/identify_chip_scan.py raw_data/2026-09-11-12-16hhi1fiber4.json --channel b27
    Verified end to end on that scan: tau_aux derived from the scan's own aux
    pair, internal reference at 573.9262 mm, facet A at 1670.2202 mm (pigtail
    1096.29 mm), facet B at 7.19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
    [2026-09-11-12-16hhi1fiber4_identified.csv, 2026-09-11-12-16hhi1fiber4_reflectogram.csv]
2026-09-14 --fiber option, and a third loopback pair found
    identify_chip_scan.py now takes the fibre number instead of the channel
    (--fiber 4..32, converted with b = 32 - fiber), and reads it straight out
    of the filename when the scan is named ...fiberNN.json, so the whole
    invocation is just the file path.
    While generating the fibre/channel/contents table from the netlist, b9/b10
    (fibres 23/22) turns out to be a **third loopback pair** with a 1034.6 um
    loop. The earlier merged-polygon analysis had missed it because the loop
    runs through four WGMETx-twin crossings, which break the polygon chain.
    The netlist confirms it: b9 reaches an SSC:o1 -- the neighbouring
    coupler's port -- at 1034.62 um.
    This is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
    [2026-09-11-12-16hhi1fiber4_identified.csv]
2026-09-14 fix miscount in the fibre table summary (10 circuit / 13 stub, not 9/14)
2026-09-14 loopback-aware anchoring and a three-panel plot for every scan
    The repeat measurement of the top loop (fibre 4, 2026-09-14) exposed three
    bugs in how facet A and facet B were anchored:
    - Single peaks were matched independently. For a loopback the topology
    fixes the answer -- there are exactly two facets and their separation is
    in the design -- so the pair with the best matching separation is now
    searched instead.
    - Instrument satellites were filtered out of the peak list but not out of
    the pair search. They ring both facets, so a satellite pair has the same
    separation as the real pair and was winning.
    - The peak clustering tolerance was 0.25 mm = 15 resolution cells, which
    merge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
    [2026-09-11-12-16hhi1fiber27_identified.csv, 2026-09-11-12-16hhi1fiber27_reflectogram.csv, 2026-09-11-12-16hhi1fiber30_identified.csv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]
2026-09-14 chain plot: absolute mm axis in panel 3, facet labels with positions
    Panel 3 of <scan>_chain.png now uses absolute distance in mm instead of
    distance behind facet A, and both facets are labelled with the position
    where their peak sits (measured facet A / facet B, plus their separation
    and the design prediction with its own mm value). The design model bar and
    the component markers move with the axis.
    Regenerated for all seven chip scans.
    [measured_b2_identified.csv]
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2026-09-14 panel 3: dashed lines at the loop start and end
    Drawn in the model colour and labelled '(model)' with their mm position,
    because nothing reflects there -- they mark where the design puts the loop,
    not a measured feature.
    Second repeat measurement (fibre 32, bottom loop) added: it reproduces to
    0.1 um (+13.2 -> +13.1 um) while the top loop repeat differs by a full
    resolution cell (-2.4 -> -19.0 um). Consistent with the top pair coupling
    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
    [2026-09-14-09-35_fiber32_reflectogram.csv]
2026-09-14 control scan analysed; panel 3 labels combined
    Control measurement (nothing connected): noise floor -67.7 dB, and the
    only features above -45 dB are the known instrument peaks at 506.4, 525.0,
    574.2 (plus satellites) and the aux leak at 2081.2 mm. In the chip window
    1660-1690 mm nothing exceeds -57.0 dB, against 0.0 dB with the chip
    connected. So the unexplained middle peaks are not an instrument artifact
    -- they need the chip. Whether they are real chip reflections or an
    artifact that requires two strong reflectors is still open; the 1034.6 um
    loop (fibres 22/23) remains the test.
    Panel 3: one combined label for the two theory values and one for the two
    measured values, 7.5 pt monospace, b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
    [2026-09-14-08-56_nichtsconnected_reflectogram.csv]
2026-09-14 retract the third loopback pair: netlist connected unrelated waveguides
    Carolina reported that fibres 22/23 are not connected at all, which turned
    out to be a bug in gds_netlist_reflectors.py: it joined *every* pair of
    ports within a component. For HHI_WGMETxE1700twin that is wrong -- the cell
    carries two independent waveguides side by side under the metal bridge,
    o1(0.3,+6.5)<->o3(29.7,+6.5) being one and o2(0.3,-6.5)<->o4(29.7,-6.5) the
    other. The old rule also joined o1<->o2, hopping 13 um across from one
    waveguide to the other, and that hop is what made the path from b9 appear
    to arrive at b10 -- the phantom 1034.6 um loop.
    New optical_pairs() decides which ports are really connected: t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
    [netlist_reflectors.csv]
2026-09-14 english docstring; analyse fibre 23
    Docstring of identify_chip_scan.py translated and brought up to date
    (700 interfaces, --fiber documented, the actual output files).
    Fibre 23 = channel b9. The fibre is connected and couples well: its
    dominant peak at 1685.6213 mm reaches 0 dB, stronger than the internal
    reference at -9.13 dB, which no earlier scan managed. Its -3 dB width is
    66.4 um against a 43.1 um window limit, so it is a blend of unresolved
    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
    [2026-09-14-09-58_fiber23_reflectogram.csv]
2026-09-14 the middle peaks are not a fixed chip reflector
    With four loopback scans (two loops x two repeats) the question is finally
    testable. Repeating the same loop moves the centroid of the middle peak
    group by 0.21 mm (fibre 32) and 0.72 mm (fibre 4), while the facets in the
    very same scans reproduce to 0.1 um and 16.6 um respectively -- a factor of
    40 to 4000. Cross-correlating the trace between the facets gives r = +0.57
    and +0.52 for repeats of the same loop against +0.54 and +0.28 for
    different loops, so a repeat is no more similar than a different structure.
    A fixed reflector in the chip would reproduce exactly, the way the facets
    do. Together with the earlier controls -- nothing above -57 d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
2026-09-14 chain plot: uniform 1660-1680mm zoom, design comparison in row 1, saved pre-rescale snapshots
    - Panel 3 (chip zoom) now uses a fixed x-window with in-view labels
    (facet A/B positions, measured vs design theory box, loop start/end
    lines) grouped into a compact label row at the top so the trace stays
    fully visible regardless of zoom width (--zoom LO HI).
    - Row 1 schematic now also states the design (GDS) facet-to-facet
    distance next to the measured one, e.g. 'measured 7.1830 mm apart |
    design 7.2020 mm (-19.0 um)', for direct comparison at a glance.
    - Applied --zoom 1660 1680 to all loopback chain plots from both
    2026-09-11 and 2026-09-14 for a consistent, readable view.
    - Saved *_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
2026-09-14 mark the RMS noise floor in every reflectogram plot
    Supervisor asked for the noise level to be visible in all plots -- without
    it a dB peak has no scale.
    New noise_floor() in process_reflectogram_aux.py. Since db is amplitude dB
    (20*log10(R/Rmax)), linear power is 10**(db/10) and the floor is
    10*log10(<power>). The mean is taken as median/ln2 rather than the plain
    mean: for a Rayleigh-distributed background both are identical, but the
    median ignores the reflector peaks, so no peak-free window has to be
    chosen by hand. Verified on the bench data -- inside a quiet window the two
    estimates agree to 0.05 dB, while over the full trace the plain mean comes
    out 10 dB too high because the peaks dom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
    [2026-09-14-08-56_nichtsconnected_reflectogram.csv]
2026-09-14 draw the RMS noise floor in every dB reflectogram plot
    Extends the previous commit from the chip plots to every script that
    draws a dB reflectogram. All of them import noise_floor() from
    process_reflectogram_aux -- one definition, no copied code.
    process_reflectogram.py single line + label
    tools/plot_reflectogram_only.py single line + label
    tools/plot_chip_chain.py rows 2 and 3, one line per loop in the
    trace's own colour
    tools/plot_band_comparison.py five traces, values in the legend
    tools/plot_fiber_comparison.py four comparison plots, per scan
    plot_tuning_diagnosis.py both traces of the left panel
    Fixed y-limi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
2026-09-16 hhi1 channel marks and netlist reflector comparison
    [hhi1_b0_fiber32_bauteile.csv, hhi1_b25_fiber7_bauteile.csv, hhi1_b26_fiber6_bauteile.csv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]
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2026-09-16 hhi1 peak/hump detection tool + findings CSVs and marked plots
    New tools/hhi_identify_peaks.py searches for spikes (over local
    median background) and humps (elevated stretches over a wider
    envelope), cross-checked against Monte-Carlo random-placement
    expectation. plot_chip_comparison.py gains --only-marks and
    --findings-csv to render/export the results.
    [hhi1_f23_befunde.csv, hhi1_f27_befunde.csv, hhi1_f30_befunde.csv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]
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2026-09-16 HHI-1 findings plots: shortened names, single facet-anchor scale bar, glossary; hump edge-case fix
    - hhi_identify_peaks.py: reuse short() component names from hhi_channel_marks
    instead of raw GDS cell names, so plot labels match across tools
    - hump_verdict: a hump that fills a design segment touches both its
    endpoints by construction; stop disqualifying it as "spans 2 interfaces"
    for that reason alone (epsilon margin instead)
    - plot_chip_comparison.py: draw the facet-A anchor uncertainty as a single
    scale bar instead of a halo around every mark (was unreadable with 24
    marks); add an auto-built glossary of the abbreviations actually used
    in each plot
    - regenerate all seven finding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
    [hhi1_f23_befunde.csv, hhi1_f27_befunde.csv, hhi1_f30_befunde.csv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]
2026-10-01 Transmissionsarm-Rechner und Setup-Skizze ergaenzt
    tools/calc_transmission_arm.py prueft Aufloesung, 150-kHz-Bandbreitengrenze,
    Rueckfaserbudget und Signalgewinn fuer einen moeglichen Transmissionsarm im
    Interferometer; gegen eigene Messdaten validiert.
2026-10-01 2026-10-01: Mk2 fast sweeps, transmission fiber 12 analysis, GDS path and zoom tools; CLAUDE.md commit rule
    [gds_paths_ch48.csv]
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2026-10-02 CAD: Fiber-Box fuer den Lina-OBR (Entwurf)
    Parametrisches CadQuery-Modell (CAD/fiberbox.py) einer auf dem Bambu Lab
    druckbaren Box: 6 gestapelte Thorlabs-BFCT-Trays auf Zentrierstiften,
    2 Tuerme a 3 Steck-Halter fuer FC-Kupplungen (Flansch 20x20x5),
    6 Wand-Kupplungen (LASER, DUT, CH1-4) mit Riegel, Rollenfach links mit
    waagrechtem Kabel-Fenster, Schiebedeckel, Schrift/Logo als Inlays.
    Kleine Druckteile (Deckel, Halter, Riegel) als STEP eingecheckt; die
    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
    [connector_holder.step, fiberholder.step, keeper.step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]
2026-10-02 CAD Fiber-Box: kompakter (212.7 x 182.9 x 107.2 mm), 1 Halter-Turm mit 3 Kupplungen pro Ebene
    [connector_holder.step, keeper.step, lid.step]
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2026-10-02 CAD: Druckteile heissen *_print.step
    [connector_holder_print.step, keeper_print.step, lid_print.step]
2026-10-02 CAD Fiber-Box: Wand-Kupplungen zum Einstecken statt Riegel, Probedruck test_print
    [connector_holder_print.step, keeper_print.step, lid_print.step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]
2026-10-02 CAD Fiber-Box: Schrift vertieft (einfarbig), Turm-Halter im Probedruck
    [connector_holder_print.step, lid_print.step, test_print.step]
2026-10-02 CAD Fiber-Box: gemessene Kupplung, Wand-Kupplung in der Wand, duenne Halter, Box 78.6 mm hoch
    [connector_holder_print.step, lid_print.step, test_print.step]
2026-10-02 CAD: Minimal-Probedruck nur mit den Connector-Haltern
    [connector_holder_print.step, lid_print.step, test_print.step]
2026-10-02 CAD Fiber-Box: Flansch-Schlitz 17 mm nach Probedruck
    [connector_holder_print.step, lid_print.step, test_print.step]
